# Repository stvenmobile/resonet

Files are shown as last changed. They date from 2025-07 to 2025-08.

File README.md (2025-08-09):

# ResoNet

**ResoNet** is an experimental platform for exploring how resonance, harmonic interaction, and physical feedback can give rise to emergent structure — without explicit instruction, training, or AI constructs.

## 🔍 Project Overview

In a universe that began as chaos and has steadily refined itself into stars, molecules, and minds, **ResoNet** is a minimalist attempt to align with that same creative force: the natural evolution of persistent patterns from vibration and feedback.

This system is designed to:

1. **Observe** a sea of external vibrations using an array of piezoelectric sensors.
2. **Intervene** in that field through controllable actuators that apply vibrational energy.
3. **Analyze** the resulting vibrational landscape for symmetry, structure, and resonance.
4. **Prefer** (but not mandate) modifications that increase order or coherence.
5. **Allow** the harmonic field to evolve — not by human design, but through emergent interaction.

> This is not an AI project (yet).  
> It is a study of whether physical systems — given the ability to sense and act — can begin to shape themselves toward *clarity*, *symmetry*, and *persistent resonance*, without needing to be told what those things mean.

## 🧱 Technical Foundations

- **Hardware**: Raspberry Pi, multiple piezo sensors, vibration actuators, ADS1115 ADCs
- **Signal Processing**: Real-time FFT, energy tracking, harmonic detection
- **Visualization**: 3D plots and spectrograms to represent vibrational structure
- **Control Loop**: Feedback cycle where the system gently modifies its own input signals and observes the result

## 🧬 Guiding Questions

- Can harmonic structures emerge in a chaotic field with minimal intervention?
- Do certain resonant patterns naturally persist over time?
- What does “preference” look like in a system without goals?
- Could this substrate eventually serve as a tool — or even a metaphor — for AI?

## 🚧 Current Status

This is the first exploratory phase:
- [x] Project name and concept defined
- [ ] Simulated sensor input and FFT visualization
- [ ] Real-time plotting of harmonic surfaces
- [ ] Hardware integration with Raspberry Pi and ADS1115
- [ ] Closed-loop resonance modification system

## 🧭 Architecture Update: Multi-Layer Physical Neural System

ResoNet now includes an experimental **two-layer resonant substrate**, where piezo disks serve as **resonators (outputs)** and **receivers (inputs)** in a physical neural network.

### Layer Design
- **Layer 1**: 4 piezo sensors mounted symmetrically on the top of the aluminum substrate
- **Layer 2**: 4 piezo sensors mounted symmetrically on the top of the aluminum substrate
- Each layer has a single 4ohm, 25w piezo resonator on the bottom side of the aluminum substrate

### Signal Generation
- A dedicated **ESP32** generates 2 independent PWM signals for the resonators
- PWM signals pass through RC filters into the LOSC Audio Amplifier
- Output from the amplifier drives the piezo resonators

### ⚡ ESP32 Signal Generator (signal_gen.ino)

This firmware runs on the ESP32 to generate two independent PWM signals for driving the left and right resonators in the ResoNet substrate. It provides both a web interface and a simple HTTP API for remote control.
Features

    Independent control of Left and Right channels

    Adjustable frequency and duty cycle per channel

    Start/Stop control per channel without losing settings

    12-bit PWM resolution (0–4095 duty internally) for extended low-frequency range

    HTTP API for scripting and automation

#### Parameters

| Parameter | Range (UI) | Range (internal) | Notes |
|---|---|---|---|
| `freqL`, `freqR` | 1 – 40000 Hz  | 1 – 40000 Hz | Practical usable range depends on resolution, amplifier, and load. At 12-bit, can drive well below 300 Hz; efficiency may drop for small exciters below ~200 Hz. |
| `dutyL`, `dutyR` | 0 – 255 | 0 – 4095 | UI values are scaled internally to 12-bit. A value of `0` stops output; near-max values can cause distortion or clipping depending on amplifier/load. |
| `leftOn`, `rightOn` | 0 or 1 | — | Enable/disable channel output without losing frequency/duty settings. |

#### HTTP API

| Endpoint | Method | Parameters | Description |
|---|---|---|---|
| `/status` | GET | — | Returns a JSON snapshot of current settings and state for both channels. |
| `/startL` | GET | — | Enables output on the left channel (uses last set frequency/duty). |
| `/stopL`  | GET | — | Disables output on the left channel (duty forced to 0). |
| `/startR` | GET | — | Enables output on the right channel (uses last set frequency/duty). |
| `/stopR`  | GET | — | Disables output on the right channel (duty forced to 0). |
| `/set` | GET | Any subset of: `freqL`, `freqR`, `dutyL`, `dutyR`, `leftOn`, `rightOn` | Updates parameters for one or both channels. Example: `/set?freqL=440&dutyL=128&leftOn=1`. |

Practical Notes

    Lower frequency limit: Software supports 1 Hz, but most small resonators/amplifiers have poor response below ~100–200 Hz.

    Upper frequency limit: PWM supports up to ~40 kHz in this config, though acoustic output >20 kHz is inaudible.

    Duty cycle: For testing, start with 100–150 (≈ 40–60% duty) in UI. Extreme values can stress hardware.

    Resolution trade-off: 12-bit resolution allows low-frequency operation but slightly reduces max achievable frequency compared to 8-bit.

### Feedback Loop
- The **Raspberry Pi** reads vibration signals from the ADS1115
- Based on the output and a training target, the Pi computes error and weight adjustments using a form of **gradient descent**
- The Pi sends new drive amplitudes to the ESP32 over UART, updating PWM duty cycles

Schematic and PCB files for the sensor PCB are in the `pcb/` directory.

### 🔬 Phase 1 Experimental Questions

- How do pure tones manifest across the plate?
- Does cross-talk occur between layers?
- How does interference affect resonance quality?
- Can spectrograms detect persistent or self-reinforcing tones?

The first phase of experimentation centers around observing and visualizing tonal patterns over time using live spectrograms.
🎯 Objective

To develop a deeper understanding of how vibrations propagate across the physical substrate, with a focus on:

    How individual tones appear in time-frequency space

    Whether resonance persists beyond a tone's duration

    How simultaneous or overlapping signals affect neighboring nodes

    Whether interference between layers leads to destructive noise or constructive resonance

This is not yet a training phase — it is a calibration and sensory tuning phase. The goal is to define and observe the characteristics of vibration, including:

    Amplitude: Intensity of the signal over time

    Frequency: Dominant and harmonic tones

    Envelope: The attack, sustain, and decay profile

    Resonance: Sustained feedback or self-reinforcement

👁️ Visualization Tool

A real-time spectrogram visualization system has been implemented. It captures piezo sensor data (via ADS1115) and displays a rolling time-frequency plot of vibration:

    Layer 1 is plotted in its own window

    Layer 2 (if active) will appear in a second subplot

    Tones played through connected actuators appear as stripes or blobs in the frequency domain

🧬 Experimental Design

Each test run spans 10 seconds, during which a predefined sequence of tones (e.g., A–B–C) is played through one layer. Variants of each experiment will modify tone timing or introduce interfering tones from the other layer:
Trial	Layer 1 Sequence	Layer 2 Tone
1	A – B – C	None
2	A – B – C	Tone during B
3	A – B – C	Tone during C
...	...	...

By comparing the spectrograms, we can analyze:

    How clearly each note registers

    Whether simultaneous tones blur or amplify

    Whether one layer becomes background noise or actively distorts the other

🔍 Broader Goal

These tests help identify useful signal characteristics that may later serve as inputs to a learning network or be used to define resonant attractor states. They also help define what "interference" and "clarity" mean in this physical system.

This process is intentionally open-ended — we are mapping the sonic and harmonic landscape to see what kinds of cognitive primitives may emerge.

 Optional Enhancement: Dual Mono Output Mode

For experiments where signal clarity, symmetry, and energy uniformity are critical, the system can be configured to operate in dual mono mode using the HiFiBerry DAC2 Pro.

In this mode, both the left and right audio channels output the same mono signal, effectively doubling the signal path and reducing distortion or channel imbalance.
✅ Benefits for Resonance Experiments

    Increased signal power: Both DAC channels reinforce the same waveform, providing greater amplitude for driving actuators.

    Improved symmetry: Eliminates phase drift or imbalance between stereo channels.

    Cleaner resonance analysis: Ideal when driving symmetrical actuator setups or when visualizing frequency harmonics in the spectrogram.

    Predictable input state: Simplifies A/B experiments by reducing the number of signal variables.

🛠️ How to Enable Dual Mono Mode

    Open the ALSA configuration:

sudo nano /etc/asound.conf

Add or replace with the following:

pcm.!default {
    type hw card 0
}
ctl.!default {
    type hw card 0
}

Enable dual mono mode via amixer:

amixer -c 0 sset 'Dual Mono' on

Test with a tone:

    speaker-test -c 2 -t sine -f 1000

You should now hear the same tone on both output channels simultaneously, confirming dual mono is active.
🧪 Experimental Use

You can now route each mono output from the DAC2 Pro or Amp2 to separate actuators (e.g., two on layer 1), confident that both channels are outputting identical and reinforced signals. This is especially useful for:

    Testing physical symmetry in the aluminum plate

    Determining resonance thresholds with maximum tone energy

    Creating baseline measurements before introducing interference from layer 2

## 🤝 Contribution

This is a solo prototype for now, but contributions, questions, and speculative discussions are welcome. Feel free to open issues or suggest papers, metaphors, or mechanisms.

## 🧠 Inspiration

> “The system clarifies the field.”

ResoNet is inspired by the idea that form and meaning can emerge — not from code or cognition — but from **structure**, **feedback**, and **resonance** itself.

---

## 🛠️ Setup Instructions

These instructions assume a Raspberry Pi 4 or 5 running Raspberry Pi OS (Bookworm) or Debian 12, with `git`, Python 3.11+, and `pip` installed.

### 1. Clone the repository

```bash
git clone git@github.com:FutureSteve/resonet.git
cd resonet
```

### 2. Create and activate a Python virtual environment

```bash
python3 -m venv venv
source venv/bin/activate
```

### 3. Install required Python packages

```bash
pip install -r requirements.txt
```

If you encounter issues with `sounddevice`, ensure `portaudio` is installed:

```bash
sudo apt install libportaudio2
```

### 4. Test tone playback

Connect your speaker or vibration transducer via amplifier, then run:

```bash
python test_tone.py
```

You should hear a brief tone. Adjust volume as needed on the amplifier.

### 5. Visualize waveform and frequency

To plot both the time-domain waveform and frequency spectrum:

```bash
python harmonic_plot.py
```

You can adjust the tone composition by modifying `harmonic_plot.py`.

---

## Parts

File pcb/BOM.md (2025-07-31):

# Bill of Materials for ResoNet Dual‑Layer PCB System

## Piezo Disks (Resonator / Sensor)
- 35 mm ceramic piezo disk, ~5 V drive / sensing, pair:
  - 6 disks for resonator side (4 for Layer 1, 2 for Layer 2)
  - 8 disks for sensor side (4 per layer)

## Amplifier Modules
- HiLetgo PAM8403 dual-channel Class D amplifier (typical breakout module)
  - Quantity: 3
  - Use: Layer 1 (2 modules), Layer 2 (1 module)

## ESP32 Module
- ESP32 DevKit (e.g. WROOM-based board with 6 usable PWM outputs)

## Power Supply
- 5 V regulated supply (e.g. 5 V USB power or bench adapter)
- Current rating: ~1 A per board (3 modules + ESP32 ≈ 1.5 A peak)

## Passive Components
- Resistors: 10 kΩ, 1% tolerance × 6
- Capacitors: 0.1 µF ceramic × 6

## MCU–PCB Interconnect
- Female‑header pins / dupont wires: for ESP32 → PAM8403 inputs
- Shielded or twisted pair wire: for piezo disk connections
- Pin headers for sensor board to stack and connect ADS1115

## ADS1115 Sensor Side
- ADS1115 ADC breakout or custom board
  - 1 board per layer (reads 4 sensor disks)
- I²C connection cables to Raspberry Pi (± SDA, SCL, VCC, GND)

## Substrate
- 1″ × 2″ aluminum sheet, 1/16″ or 1/8″ thick (~0.5–1.5 mm)
- Mounting tape or silicone adhesive (non-stiffening)

## Miscellaneous
- Prototyping board for mounting RC filters (or direct wire)
- Zip ties or supports to fix modules near substrate edges

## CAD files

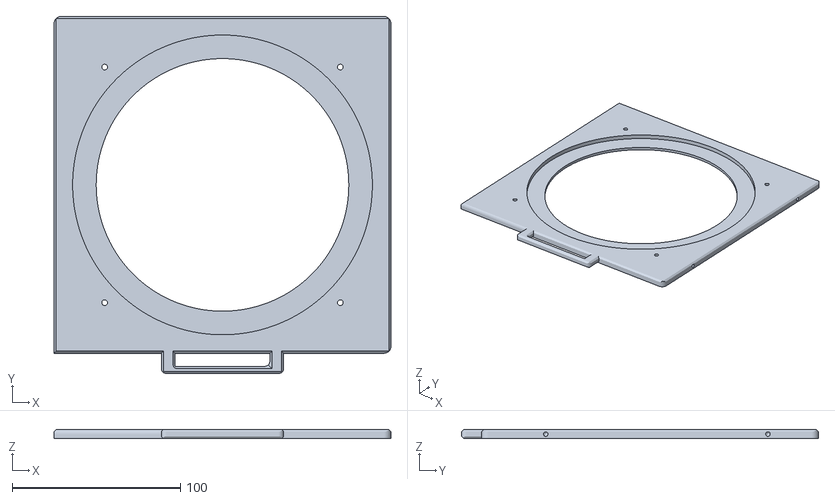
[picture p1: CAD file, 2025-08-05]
hardware/stl/Tray_2.stl
200.0 x 212.0 x 5.18

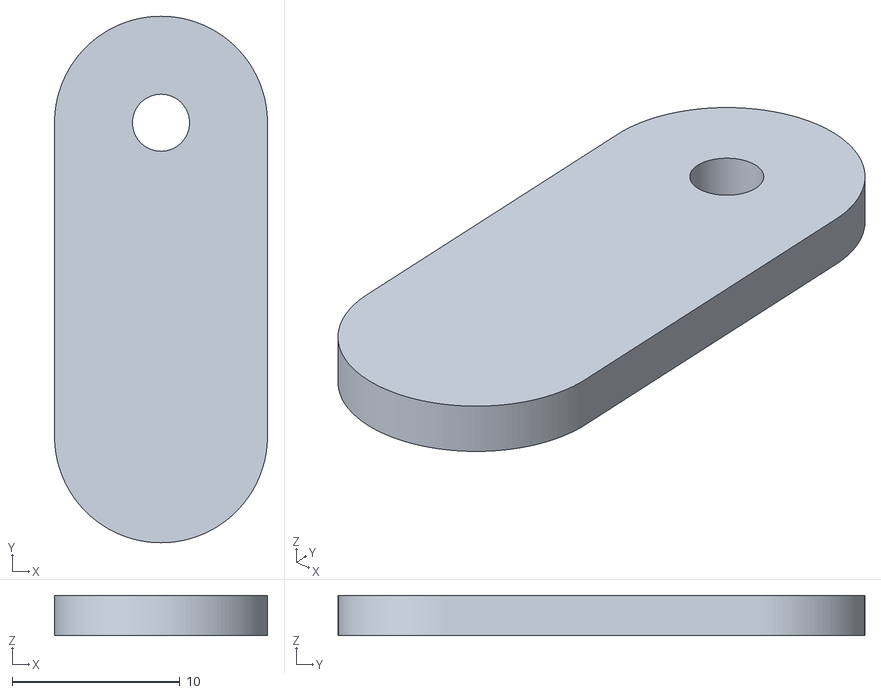
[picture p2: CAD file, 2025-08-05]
hardware/stl/Clip_3.stl
12.7 x 31.4 x 2.40

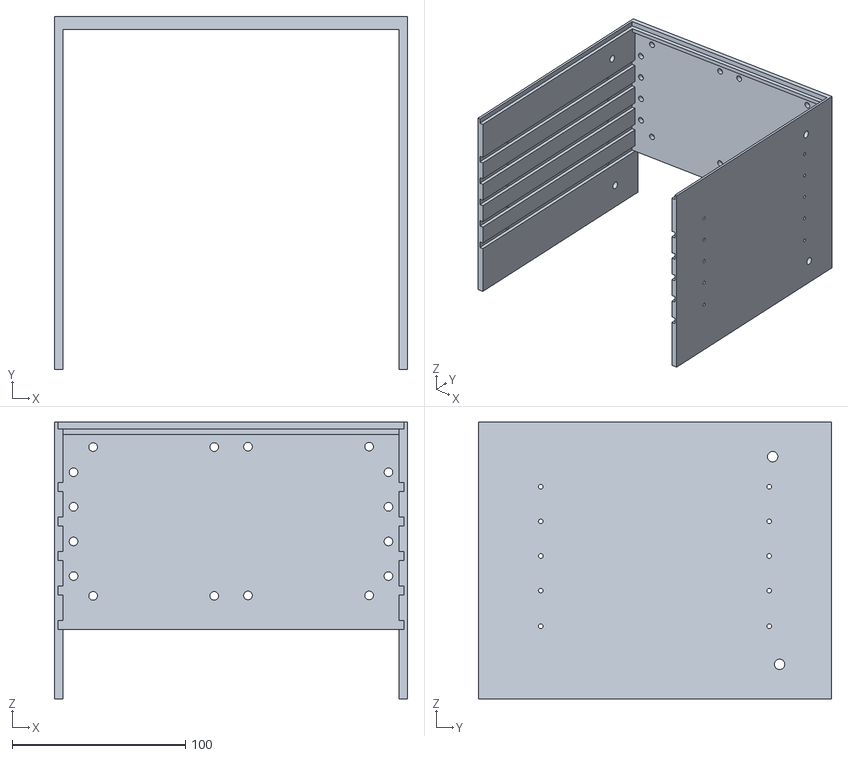
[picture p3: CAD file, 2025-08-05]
hardware/stl/shell.stl
204.0 x 204.0 x 160.0

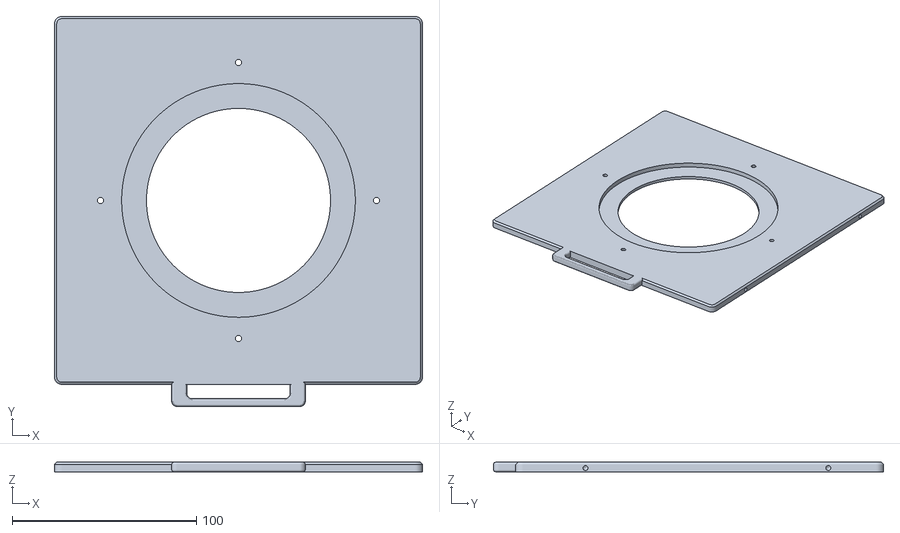
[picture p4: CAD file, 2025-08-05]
hardware/stl/Tray_1.stl
200.0 x 212.0 x 5.18

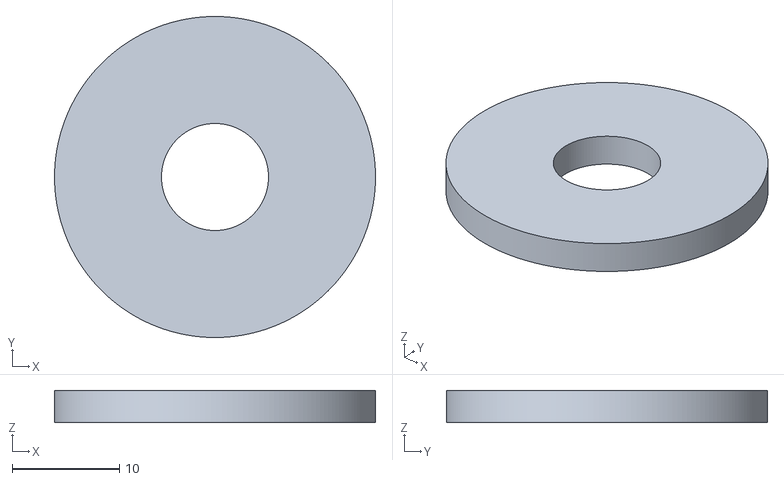
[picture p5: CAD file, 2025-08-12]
hardware/stl/Washer.stl
30.0 x 30.0 x 3.00

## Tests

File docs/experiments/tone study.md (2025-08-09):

## Sample Experiment: Tone Interference Study

1. Play tone A (800 Hz) on Layer 1.
2. At 5 seconds, play tone B (1000 Hz) on Layer 2.
3. Observe whether layer 1 spectrogram shows harmonic interaction.

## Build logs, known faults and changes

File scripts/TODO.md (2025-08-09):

- [ ] Plot dual-layer spectrograms in real time
- [ ] Define JSON command protocol for ESP32 tone control
- [ ] Create synthetic tone playback sequences from MIDI or CSV
- [ ] Detect harmonics above base frequency in FFT

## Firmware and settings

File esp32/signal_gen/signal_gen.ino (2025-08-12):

#include <Arduino.h>
#include <WiFi.h>
#include <AsyncTCP.h>
#include <ESPAsyncWebServer.h>

// ====== USER CONFIG ======
const char* WIFI_SSID = "googlewifi";    // <-- set your SSID
const char* WIFI_PASS = "abc123def456"; // <-- set your password
// =========================

// Pins
const int leftPWM  = 4;
const int rightPWM = 5;

// Defaults (UI ranges)
int freqL  = 440;   // Hz
int freqR  = 523;   // Hz
int dutyL8 = 127;   // 0..255 (UI) -> scaled to 12-bit
int dutyR8 = 127;   // 0..255 (UI)

// Channel enable states
bool leftEnabled  = true;
bool rightEnabled = true;

// LEDC config
const uint8_t  resBits = 12;                  // 12-bit => 0..4095 duty
const uint32_t dutyMax = (1u << resBits) - 1; // 4095

// Safety limits
const uint32_t F_MIN = 1;
const uint32_t F_MAX = 40000;

AsyncWebServer server(80);

// ---------- Utils ----------
static inline uint32_t clampU32(uint32_t v, uint32_t lo, uint32_t hi){
  if (v < lo) return lo;
  if (v > hi) return hi;
  return v;
}

// Scale 0..255 (UI) -> 0..dutyMax (LEDC)
static inline uint32_t scaleDuty(uint32_t d8){
  return (d8 * dutyMax + 127) / 255;
}

static String jsonStatus() {
  uint32_t effL = leftEnabled  ? scaleDuty(clampU32(dutyL8, 0, 255)) : 0;
  uint32_t effR = rightEnabled ? scaleDuty(clampU32(dutyR8, 0, 255)) : 0;
  String ip = (WiFi.status() == WL_CONNECTED) ? WiFi.localIP().toString() : "0.0.0.0";

  String s = "{";
  s += "\"ip\":\"" + ip + "\",";
  s += "\"freqL\":" + String(freqL) + ",";
  s += "\"freqR\":" + String(freqR) + ",";
  s += "\"dutyL8\":" + String(dutyL8) + ",";
  s += "\"dutyR8\":" + String(dutyR8) + ",";
  s += "\"dutyL_eff\":" + String(effL) + ",";
  s += "\"dutyR_eff\":" + String(effR) + ",";
  s += "\"leftEnabled\":" + String(leftEnabled ? "true" : "false") + ",";
  s += "\"rightEnabled\":" + String(rightEnabled ? "true" : "false") + ",";
  s += "\"resolution_bits\":" + String(resBits);
  s += "}";
  return s;
}

static void sendJSON(AsyncWebServerRequest* req, const String& body, int status=200) {
  AsyncWebServerResponse *res = req->beginResponse(status, "application/json", body);
  res->addHeader("Cache-Control", "no-store");
  req->send(res);
}

// ---------- UI ----------
String page() {
  // Note: using &bull; for bullets and declaring UTF-8 in <head>.
  String html = R"HTML(
<!doctype html>
<html>
<head>
  <meta charset="UTF-8">
  <meta name=viewport content="width=device-width, initial-scale=1">
  <title>ResoNet Control</title>
  <style>
    :root{--fg:#111;--mut:#666}
    body{font-family:system-ui;margin:20px;max-width:720px;color:var(--fg)}
    h3{margin:.25rem 0 1rem}
    .grid{display:grid;grid-template-columns:1fr 1fr;gap:16px}
    .card{border:1px solid #ddd;border-radius:10px;padding:12px;box-shadow:0 1px 2px rgba(0,0,0,.04)}
    label{display:block;font-size:.9rem;color:var(--mut);margin:.25rem 0}
    input{width:100%;padding:.45rem;border:1px solid #ccc;border-radius:8px}
    .row{margin:.5rem 0}
    .btnbar{display:flex;gap:8px;flex-wrap:wrap;margin-top:.5rem}
    button{padding:.5rem .9rem;border-radius:8px;border:1px solid #ccc;background:#f7f7f7;cursor:pointer}
    button.primary{background:#eef6ff;border-color:#b6d4ff}
    .status{font-size:.9rem;color:var(--mut)}
    code{background:#f2f2f2;padding:.1rem .3rem;border-radius:4px}
    .mono{font-family:ui-monospace, SFMono-Regular, Menlo, Consolas, monospace}
  </style>
</head>
<body>
  <h3>ESP32 PWM Control (STA mode)</h3>

  <div class="grid">
    <div class="card">
      <h4>Left Channel</h4>
      <form action="/set" method="get">
        <div class="row">
          <label>Frequency (Hz)</label>
          <input name="freqL" type="number" min="1" max="40000" required>
        </div>
        <div class="row">
          <label>Duty (0-255)</label>
          <input name="dutyL" type="number" min="0" max="255" required>
        </div>
        <div class="btnbar">
          <button class="primary" type="submit" name="leftOn" value="1">Start Left</button>
          <button type="submit" name="leftOn" value="0">Stop Left</button>
          <button type="submit">Apply (Left)</button>
        </div>
      </form>
      <p class="status">State: <b id="ls"></b> &bull; F=<span id="fl"></span> Hz &bull; Duty=<span id="dl"></span></p>
    </div>

    <div class="card">
      <h4>Right Channel</h4>
      <form action="/set" method="get">
        <div class="row">
          <label>Frequency (Hz)</label>
          <input name="freqR" type="number" min="1" max="40000" required>
        </div>
        <div class="row">
          <label>Duty (0-255)</label>
          <input name="dutyR" type="number" min="0" max="255" required>
        </div>
        <div class="btnbar">
          <button class="primary" type="submit" name="rightOn" value="1">Start Right</button>
          <button type="submit" name="rightOn" value="0">Stop Right</button>
          <button type="submit">Apply (Right)</button>
        </div>
      </form>
      <p class="status">State: <b id="rs"></b> &bull; F=<span id="fr"></span> Hz &bull; Duty=<span id="dr"></span></p>
    </div>
  </div>

  <div class="card" style="margin-top:16px">
    <h4>API</h4>
    <p class="mono">GET <code>/status</code></p>
    <p class="mono">GET <code>/startL</code> &bull; <code>/stopL</code> &bull; <code>/startR</code> &bull; <code>/stopR</code></p>
    <p class="mono">GET <code>/set?freqL=440&dutyL=127&leftOn=1</code></p>
    <p class="mono">GET <code>/set?freqR=523&dutyR=64&rightOn=0</code></p>
    <p class="status">Resolution: 12-bit (0&ndash;4095 internal). Lower frequencies enabled.</p>
  </div>

  <script>
    const curr = {
      freqL: )HTML";
  html += String(freqL);
  html += R"HTML(, freqR: )HTML";
  html += String(freqR);
  html += R"HTML(, dutyL: )HTML";
  html += String(dutyL8);
  html += R"HTML(, dutyR: )HTML";
  html += String(dutyR8);
  html += R"HTML(, leftOn: )HTML";
  html += String(leftEnabled ? 1 : 0);
  html += R"HTML(, rightOn: )HTML";
  html += String(rightEnabled ? 1 : 0);
  html += R"HTML( };

    // Left form fields
    const lf = document.querySelectorAll('form')[0];
    lf.querySelector('[name=freqL]').value = curr.freqL;
    lf.querySelector('[name=dutyL]').value = curr.dutyL;

    // Right form fields
    const rf = document.querySelectorAll('form')[1];
    rf.querySelector('[name=freqR]').value = curr.freqR;
    rf.querySelector('[name=dutyR]').value = curr.dutyR;

    // Status text
    fl.textContent = curr.freqL;
    fr.textContent = curr.freqR;
    dl.textContent = curr.dutyL;
    dr.textContent = curr.dutyR;
    ls.textContent = curr.leftOn ? "Running" : "Stopped";
    rs.textContent = curr.rightOn ? "Running" : "Stopped";
  </script>

</body>
</html>
)HTML";
  return html;
}

// ---------- PWM control ----------
void writeOutputs() {
  uint32_t dL = leftEnabled  ? scaleDuty(clampU32(dutyL8, 0, 255)) : 0;
  uint32_t dR = rightEnabled ? scaleDuty(clampU32(dutyR8, 0, 255)) : 0;
  ledcWrite(leftPWM,  dL);
  ledcWrite(rightPWM, dR);
}

void applyPwmInit() {
  ledcAttach(leftPWM,  clampU32(freqL, F_MIN, F_MAX), resBits);
  ledcAttach(rightPWM, clampU32(freqR, F_MIN, F_MAX), resBits);
  writeOutputs();
}

void applyPwmLive() {
  ledcChangeFrequency(leftPWM,  clampU32(freqL, F_MIN, F_MAX), resBits);
  ledcChangeFrequency(rightPWM, clampU32(freqR, F_MIN, F_MAX), resBits);
  writeOutputs();
}

// ---------- WiFi ----------
void connectWifiSTA() {
  WiFi.mode(WIFI_STA);
  WiFi.begin(WIFI_SSID, WIFI_PASS);
  Serial.printf("Connecting to %s", WIFI_SSID);
  unsigned long start = millis();
  while (WiFi.status() != WL_CONNECTED && millis() - start < 20000) {
    delay(300);
    Serial.print(".");
  }
  Serial.println();
  if (WiFi.status() == WL_CONNECTED) {
    Serial.print("WiFi connected. IP: ");
    Serial.println(WiFi.localIP());
  } else {
    Serial.println("WiFi connect timed out; continuing anyway. (Server will fail without network.)");
  }
}

// ---------- HTTP ----------
void handleSet(AsyncWebServerRequest *req){
  if (req->hasParam("freqL"))  freqL  = req->getParam("freqL")->value().toInt();
  if (req->hasParam("freqR"))  freqR  = req->getParam("freqR")->value().toInt();
  if (req->hasParam("dutyL"))  dutyL8 = req->getParam("dutyL")->value().toInt();
  if (req->hasParam("dutyR"))  dutyR8 = req->getParam("dutyR")->value().toInt();

  if (req->hasParam("leftOn"))  leftEnabled  = (req->getParam("leftOn")->value().toInt()  != 0);
  if (req->hasParam("rightOn")) rightEnabled = (req->getParam("rightOn")->value().toInt() != 0);

  freqL  = clampU32(freqL,  F_MIN, F_MAX);
  freqR  = clampU32(freqR,  F_MIN, F_MAX);
  dutyL8 = clampU32(dutyL8, 0, 255);
  dutyR8 = clampU32(dutyR8, 0, 255);

  applyPwmLive();
  req->redirect("/");
}

void handleStatus(AsyncWebServerRequest *req){ sendJSON(req, jsonStatus()); }
void handleStartL(AsyncWebServerRequest *req){ leftEnabled = true;  writeOutputs(); sendJSON(req, jsonStatus()); }
void handleStopL (AsyncWebServerRequest *req){ leftEnabled = false; writeOutputs(); sendJSON(req, jsonStatus()); }
void handleStartR(AsyncWebServerRequest *req){ rightEnabled = true; writeOutputs(); sendJSON(req, jsonStatus()); }
void handleStopR (AsyncWebServerRequest *req){ rightEnabled = false;writeOutputs(); sendJSON(req, jsonStatus()); }

void setup() {
  Serial.begin(115200);
  delay(200);

  connectWifiSTA();
  applyPwmInit();

  server.on("/",       HTTP_GET, [](AsyncWebServerRequest *req){ req->send(200, "text/html", page()); });
  server.on("/set",    HTTP_GET, [](AsyncWebServerRequest *req){ handleSet(req); });
  server.on("/status", HTTP_GET, [](AsyncWebServerRequest *req){ handleStatus(req); });
  server.on("/startL", HTTP_GET, [](AsyncWebServerRequest *req){ handleStartL(req); });
  server.on("/stopL",  HTTP_GET, [](AsyncWebServerRequest *req){ handleStopL(req); });
  server.on("/startR", HTTP_GET, [](AsyncWebServerRequest *req){ handleStartR(req); });
  server.on("/stopR",  HTTP_GET, [](AsyncWebServerRequest *req){ handleStopR(req); });

  server.begin();
  Serial.println("HTTP server started.");
}

void loop() {
  // AsyncWebServer handles requests
}

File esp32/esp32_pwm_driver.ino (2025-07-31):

const int pwmPins[] = {12, 13, 14, 15, 16, 17};  // 6 channels
int weights[6] = {128, 128, 128, 128, 128, 128};  // default duty cycle

void setup() {
  for (int i = 0; i < 6; i++) {
    ledcSetup(i, 5000, 8);        // Channel, 5kHz, 8-bit resolution
    ledcAttachPin(pwmPins[i], i); // Attach PWM channel to GPIO
    ledcWrite(i, weights[i]);
  }

  Serial.begin(115200);  // UART for receiving weight updates
}

void loop() {
  if (Serial.available() >= 6) {
    for (int i = 0; i < 6; i++) {
      weights[i] = Serial.read();
      ledcWrite(i, weights[i]);
    }
  }
}

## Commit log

2025-07-30 PCB information for sensor board and updates to README.
    Changing the overall design to be a multi-layer perceptron using resonance for discrimination. Instead of a single large resonator, each piezo sensor will have an associated piezo resonator. The reso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
    [resonet.fzz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]
2025-07-31 Add BOM
    Added BOM.md and esp32_pwm_driver.ino files.
2025-08-05 Added STL files and updated README.md
    Added STL files for the 3D printed case and trays. Updated README.md file with DUAL MONO mode documentation.
    [Clip_3.stl, Tray_1.stl, Tray_2.stl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]
2025-08-05 Added PCB information to docs
2025-08-05 updated project structure
    [Clip_3.stl, Tray_1.stl, Tray_2.stl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]
2025-08-09 Create signal_gen.ino
    Script to generate tone signals on lefty and right channel using ESP32 PWM on pins GPIO4 and GPIO5.
2025-08-12 Updated schematics.
    [Washer.stl, esp32s3_8ch_adc_frontend_kicad9.kicad_sch]
